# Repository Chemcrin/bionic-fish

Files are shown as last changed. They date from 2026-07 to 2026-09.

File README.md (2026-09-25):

# 仿生鱼工程 · BionicFish

> 一只可在水下游动的仿生潜航器 —— 由**项目组主导、组员协作、AI Agent 辅助**，完成从机械结构设计、电控硬件、嵌入式固件到 Android 上位机的全栈工程实现。外形参考「追鲨一号」构型，结构自主设计。**整机已完成实际下水运行（泳池 / 静水实测）**，面向课程设计、教学演示与水下任务原型验证。

<p align="center">
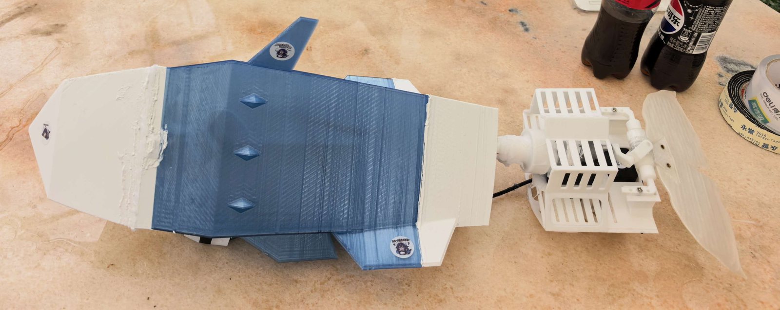
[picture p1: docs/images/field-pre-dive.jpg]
整机下水前实拍
  
</p>
<p align="center"><em>整机实拍 —— 头 / 体 / 尾三段分件，尾部曲柄摇杆传动与尾鳍外露可见</em></p>

<p align="center">
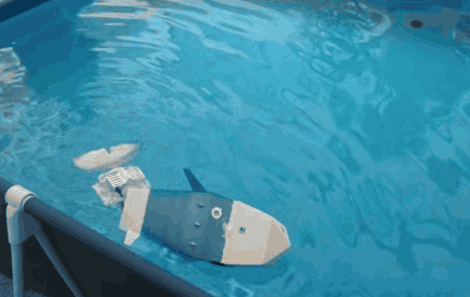
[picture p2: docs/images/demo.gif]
整机在泳池中游动的实拍演示
  
</p>
<p align="center"><em>实机演示 —— 整机在泳池中自主游动，尾鳍摆动推进；完整 24 秒视频见 <a href="docs/media/demo.mp4">docs/media/demo.mp4</a></em></p>

<p align="center">
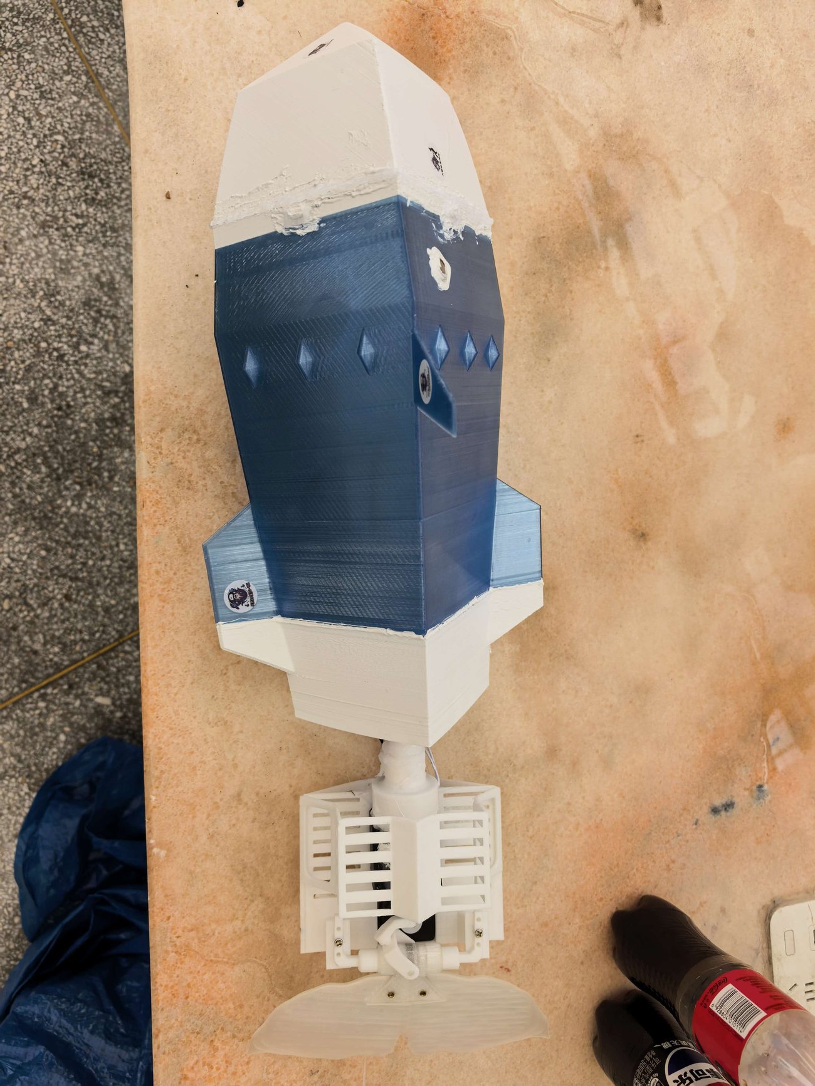
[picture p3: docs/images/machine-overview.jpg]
整机俯视实拍
  
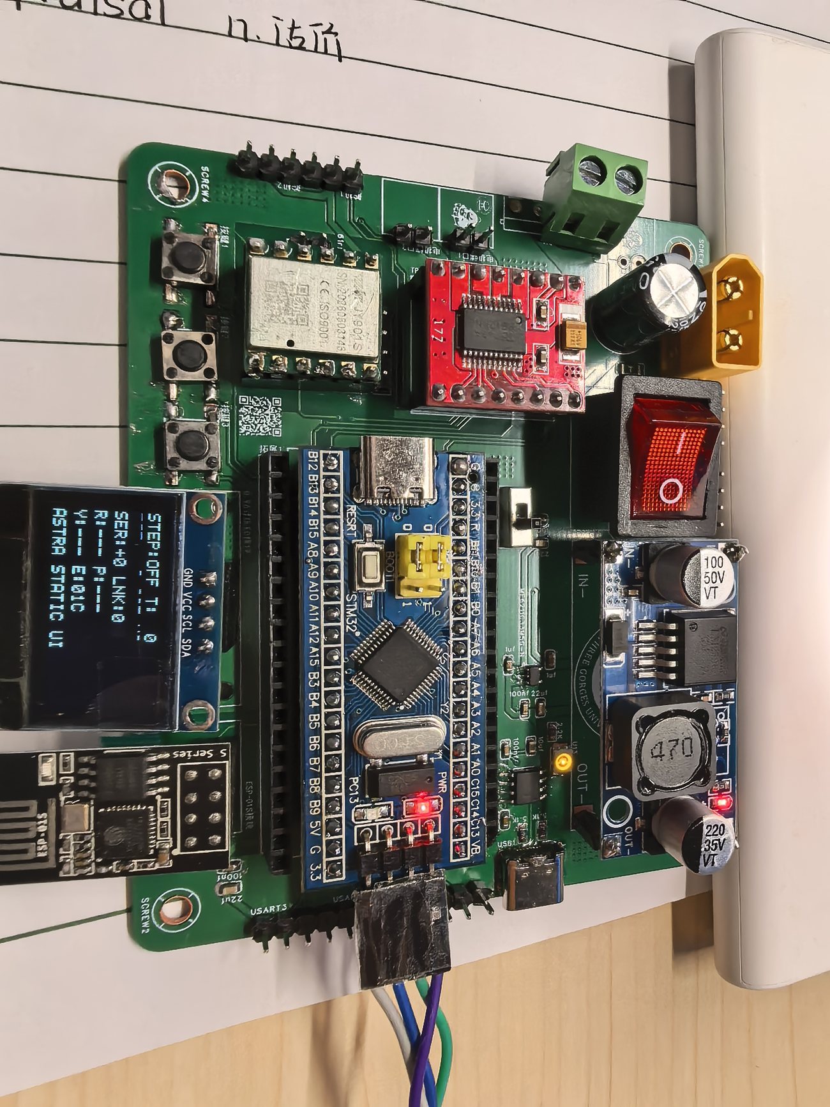
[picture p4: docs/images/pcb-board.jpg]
自研拓展板实装照片
  
</p>
<p align="center"><em>左：整机俯视（白色头部 / 蓝色鱼体 / 白色尾段）；右：自研拓展板实装 —— TB6612、ESP-01S、CH340 + Type-C、OLED、XT60 与 LM2596S 全部可拔换</em></p>

<p align="center">
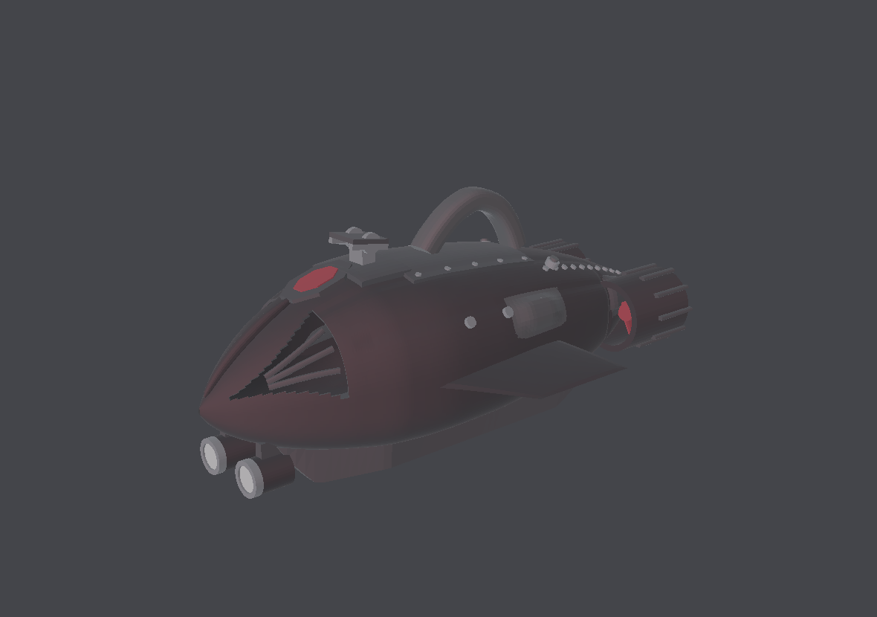
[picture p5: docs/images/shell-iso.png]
外壳外观设计渲染
  
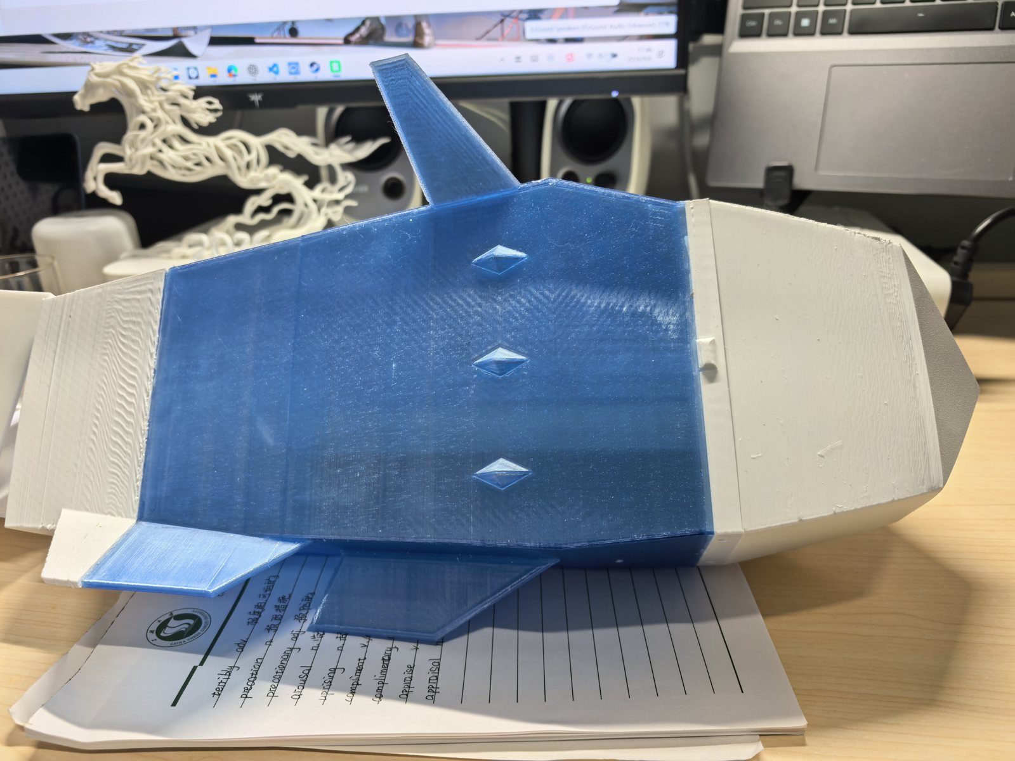
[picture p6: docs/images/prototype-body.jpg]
3D 打印实物
  
</p>
<p align="center"><em>外观设计渲染与 3D 打印实物</em></p>

**开源地址：** [Chemcrin/bionic-fish](https://github.com/Chemcrin/bionic-fish)

> 🤖 **本项目由项目组与 AI Agent 协作开发。** 硬件方案推演、固件与协议实现、上位机、以及本文档本身，都在一个「AI Agent 可闭环」的流程中完成 —— 项目为此专门设计了 **ST-Link SWD 烧录 + 板载 CH340 串口日志**的双通道调试环境（见 [3.5.2](#352-板载-ch340-的实战价值双接-ai-agent-联合调试)），让工具能直接跑通「改代码 → 烧录 → 读日志 → 再改」的迭代闭环。
>
> **如果你也打算复刻，我们鼓励你同样合理地使用 AI 助理工具辅助复刻** —— 让工具去承担资料检索、样板代码、协议解析与日志排错，把人的精力留给机械取舍、电气判断与实机验证。
>
> ⚠️ 但请守住底线：AI 产出的内容**必须经过你自己的复核与实测**。尤其是电源极性、接线顺序、保险丝规格与下水安全相关的部分，**不要未经确认就直接照抄执行**。

---

## 目录

- [一、项目概述](#一项目概述)
- [二、系统总体架构](#二系统总体架构)
- [三、硬件与电气设计](#三硬件与电气设计)
- [四、外观与结构设计](#四外观与结构设计)
- [五、控制方式与通信系统](#五控制方式与通信系统)
- [六、代码架构](#六代码架构)
- [七、上位机与控制台](#七上位机与控制台)
- [八、仓库结构](#八仓库结构)
- [九、快速开始](#九快速开始)
- [📖 复刻指南（硬件制造 / 通信调试 / 电控编写）](docs/复刻指南/README.md)

---

## 一、项目概述

本项目制作一只用于水下任务演示的仿生潜航器。整机以**稳定性与可控性优先**为设计原则，不追求高速。

**这是由项目组主导、组员协作完成的全栈工程** —— 从外形与机械结构设计、电控硬件选型与拓展板搭建、嵌入式固件开发，到 Android 上位机与控制协议定义，均由项目组自行设计与实现（开发全程借助 AI Agent 辅助，见文首说明），未采用现成开源飞控/机器人框架套用。

| 维度 | 指标 |
| --- | --- |
| 外形 | 参考「追鲨一号」潜航器外形，**自主完成整机结构设计**，全长 **700 mm** |
| 壳体 | PETG 3D 打印，壁厚 **3.2 mm**，分段式（头 / 体 / 尾） |
| 推进 | **370 直流减速电机**驱动尾段 |
| 沉浮 | **注射器式浮力调节唧筒**，由 **N20 直流减速电机**（12 V 版）经齿轮螺杆驱动活塞 |
| 转向 | **IP65 舵机**，安全行程 **±15°** |
| 电控 | STM32F103C8T6 主控 + ESP-01S Wi-Fi + TB6612 双 H 桥 |
| 姿态 | JY901S（兼容 JY61P 协议）9 轴 IMU，软件 I²C |
| 显示 | SSD1306 128×64 OLED 单页状态屏 |
| 供电 | 3S 航模锂电池（45C），VM ≈ 12 V |
| 上位机 | Android「仿生鱼控制台」v0.5.0，Wi-Fi TCP AP 直连 |

### 1.1 项目难点与特点

| 特点 | 说明 |
| --- | --- |
| **全栈自研** | 机械结构、电路、固件、协议、上位机 App、网页控制台六层全部由项目组自行打通（全流程有 AI Agent 辅助，见文首说明；制作与验证环节由组员协作承担）。跨层改动需要同时理解机械约束、时序约束与协议兼容性。 |
| **机械结构自主设计** | 外壳、尾部曲柄摇杆传动、唧筒沉浮机构、快拆结构与各支撑件均为自研。尾部支撑经 V2→V3R→V4R→**V6/V4F** 多轮迭代收敛；唧筒从零设计出「N20 + 齿轮减速 + 螺杆自锁 + 双微动开关限位」的完整传动链。 |
| **参数化外壳建模** | 用 Python 以型线表驱动生成 700 mm 整机外观（90,068 三角面），改参数即可调整线型，再导出 STL/STEP 供 3D 打印与 CAD 后续加工。 |
| **从零定义通信协议** | 自研 V1 ASCII 协议：换行分帧、序号窗口防重放与乱序、故障位图并存多故障、失联 1 s 安全停机。协议同时被 Android App 与板载网页控制台复用。 |
| **裸机实时固件** | 6,000 行 C，无 RTOS，64 KiB Flash / 20 KiB RAM 内跑通双电机、舵机、IMU、OLED、TCP 服务与网页托管。 |
| **可替换、可观测的硬件设计** | 自研拓展板：32 针母座固定核心板、UART 与电机舵机接口全排针扇出、全模组可拔换；板载 CH340 与 SWD 构成**双通道并行调试**，为 AI Agent 辅助开发提供了可闭环的烧录 + 日志通路。 |
| **板级电气与电源自主设计** | 逻辑轨用 ME6211 LDO（低噪声，护住 IMU），动力轨用 LM2596S DCDC（高效率，带电机）；XT60 与咪头双输入适配，5 A 一次性保险丝兜底短路保护。 |
| **踩穿硬件级陷阱** | 自行定位 100% 占空比导致 TB6612 自举电容无法刷新的隐性故障，并留下编译期门禁防止同类问题静默复发（见第三章 3.4）。 |
| **已实际下水运行** | 整机装配完成后**真实入水运行**，在泳池 / 静水环境验证密封、配重、姿态与基本机动（前进、转向、安全停机），不是只停留在台架或仿真阶段。 |

**首版定位**：无线遥控 + 半自动控制原型，核心目标是验证「能游、能控、能安全停机」—— 该目标已通过整机下水实测确认；视觉自主与深度闭环留待第二阶段增强。

> ⚠️ 本项目为教学原型，**已在泳池 / 静水环境完成整机下水运行实测**。但**长时间深水作业、复杂水域与自主任务能力尚未验证**；软件测试通过也不等于任意环境下都可用。每次下水前仍请确认已装好机械保护、可立即断电，并已完成台架启停、失联与供电恢复测试。

> 📌 **关于文中「需实测确认」的表述**：软件层证据（host 回归、Android 单元/仪器测试、实板烧录与 USART3 诊断）与整机下水是**两套独立证据**。文中标注为「待实板」「需实测」的条目，指**尚未做过逐项定量标定**的项目（如堵转电流、TB6612 温升、动密封长期衰减），不代表整机未下水。

---

## 二、系统总体架构

```text
┌──────────────────────────────────────────────┐
│         Android 控制台「仿生鱼控制台」          │
│   M1 方向 ／ M2 唧筒 ／ 舵机 ±15° ／ 急停       │
└───────────────────┬──────────────────────────┘
                    │ Wi-Fi：BionicFish-AP
                    │ TCP 192.168.4.1:9000
┌───────────────────▼──────────────────────────┐
│              ESP-01S（ESP8266）               │
│   AT 固件 1.7.4.0 ｜ 纯 SoftAP ｜ TCP Server   │
└───────────────────┬──────────────────────────┘
                    │ UART0 ↔ USART2　115200-8N1　无流控
┌───────────────────▼──────────────────────────┐
│           STM32F103C8T6　SYSCLK 72 MHz        │
│  ┌────────────────────────────────────────┐  │
│  │ TIM2 ── PWM ──► TB6612 ─┬─ A 桥 ─► M1 370 推进 │
│  │                         └─ B 桥 ─► M2 N20 唧筒 │
│  │ TIM3 CH1 ── 50 Hz 脉冲 ──► 舵机 PA6     │  │
│  │ 软件 I²C PB6/PB7 ──► JY901S 姿态         │  │
│  │ 软件 I²C PB8/PB9 ──► SSD1306 状态屏      │  │
│  │ USART3 ──► CH340 ──► 调试/诊断输出      │  │
│  └────────────────────────────────────────┘  │
│  ▲ 32 针母座固定 ── UART/电机/舵机全排针扇出   │
└──────────────────────────────────────────────┘
        ▲ SWD                              ▲ USART3
   ┌────┴─────┐                      ┌─────┴──────┐
   │ ST-Link  │                      │ CH340(Type-C)│
   └────┬─────┘                      └─────┬──────┘
        └────────► 同一台主机 ◄────────────┘
              烧录 + 串口日志 双接并行调试
```

**电源链路**：

```text
XT60 / 咪头 ──► 5 A 一次性保险丝 ──► LM2596S (DCDC, 可调)
                                        │
                              ┌─────────┴──────────┐
                              ▼                    ▼
                        动力轨：TB6612 VM、舵机   5 V 中间轨
                                                   │
                                                   ▼
                                        ME6211 (LDO) ─► 3.3 V 逻辑轨
                                        MCU / ESP / IMU / OLED / CH340
```

**两条执行链路分工**：

- **M1（370）→ 尾段推进**：决定「往哪游」，通过尾段摆动产生前进推力与航向；
- **M2（N20）→ 唧筒活塞**：决定「在哪个深度」，通过注射器式容积变化改变排水量，从而调节浮力实现上浮/下潜。

这两路共用一个 TB6612 的两个 H 桥，因此**共用同一 PWM 挡位**，但方向各自独立 —— 推进与沉浮可以同时动作。

**信息流是双向的**：命令从 Android 经 ESP 下达到 STM32；状态帧（`STA`）从 STM32 周期回传，经 ESP 与 CH340N 双路输出，让手机端与串口调试端能同时观察整机状态。

---

## 三、硬件与电气设计

### 3.1 选型对比与决策依据

> 📐 **总体设计思路沿用 TI 杯电子设计竞赛的工程范式**：主控 + 功能模组的积木式组合，每个模组独立供电、独立接口、可单独替换与单独测试，全链路信号都留可测量的测试点。这一取向直接决定了下面几乎每一行的取舍 —— 宁可多花几块钱买成熟模组，也不把风险藏进自绘 PCB 里。

| 环节 | 候选方案 | 最终选择 | 适宜性 | 经济性 | 稳定性 |
| --- | --- | --- | --- | --- | --- |
| **主控** | STM32F103ZET6 / **C8T6** / ESP32 单主控 | **STM32F103C8T6** | 需 5 路 PWM + 2 路 UART + 2 路软 I²C，C8T6 的 37 个 GPIO、16 路定时器通道完全覆盖且有余量；硬件 FPU 与算力对本任务无刚需 | LQFP48 最小系统板约 ¥10–15，远低于 ZET6；生态成熟、资料丰富 | 工业级 Cortex-M3，HAL 库稳定；无操作系统裸机调度，无 RTOS 任务抖动风险 |
| **板级架构** | 自绘一体式 PCB / **核心板 + 拓展板** | **核心板 + 自研拓展板** | 拓展板只做引脚扇出与电源分配，不做信号处理，故障定位边界清晰；核心板可单独取下用 ST-Link 烧录与替换 | 拓展板单次打样即可，改版只需重画扇出层，不牵动主控电路 | 任一功能模组异常时可直接拔换排查，不必怀疑板上焊接；核心板损坏只需换最小系统板 |
| **调试 / 烧录** | 仅 SWD / 仅串口 / **SWD + 板载串口双通道** | **ST-Link SWD + 板载 CH340 Type-C 双接** | 两种通道各司其职：SWD 负责烧录与断点，CH340 负责运行期日志与协议观测 | CH340 芯片约 ¥2，省掉一个外置 USB-TTL 模块与接线工序 | 双通道互为备份；SWD 被占或接触不良时，串口仍能观察到状态帧 |
| **无线通信** | 自绘 ESP8266 透明桥 / ESP32 WebSocket / **ESP-01S AT** | **ESP-01S + AT 固件** | 只需 TCP 透传，AT 模式无需自维护固件；UART 一条线接入即可 | 模组约 ¥8，无需额外 PCB 打样与烧录工装 | 官方 AT 固件经长期验证；每次 AT 事务带响应确认，链路状态可观测 |
| **电机驱动** | L298N / **TB6612FNG** / 分立 MOS H 桥 | **TB6612FNG** | 单芯片双 H 桥，正好驱动 M1 推进与 M2 唧筒两路，PWM 频率范围宽 | 模块约 ¥6，比 L298N 便宜且体积小一半 | 导通电阻低、发热小、自带热关断；无需自绘 H 桥即可获得可靠驱动 |
| **推进方式** | 42 两相双极步进 / **直流减速电机** | **370 直流减速电机** | 直流电机直接调压调速，无需换相表、相序配对与步距角标定，工程复杂度大幅下降 | 370 减速电机约 ¥15，无需专用步进驱动器 | 两根线接入，接反只会反转，不会像步进那样抖动/堵转；无失步风险 |
| **沉浮方式** | 中性浮力 + 鳍面控制 / 可移动配重 / **注射器式唧筒** / 微型水泵 | **注射器式浮力调节唧筒**（N20 驱动） | 通过活塞改变排水体积主动调节浮力，可**原地定深**，不依赖前进速度；相比水泵方案无管路与水泵密封难题 | 100 ml 注射器 + N20 减速电机 + 齿轮螺杆，成本远低于水泵浮力舱 | 机械容积式调节，状态可复现；配双微动开关做行程限位 |
| **姿态传感器** | MPU6050 / **JY 系列** | **JY901S**（兼容 JY61P） | 模块内部完成姿态解算，直接读角度寄存器，主控零算力开销 | 约 ¥50，省去自写互补滤波/Kalman 的开发成本 | 内部温补与磁力计融合，Yaw 为绝对航向而非陀螺积分漂移 |
| **舵机** | 普通舵机 / **IP65 防水舵机** | **IP65 防水舵机** | 水下环境刚需 | 略贵但省去额外防水结构 | 工厂封装防水，可靠性远高于自制密封 |
| **显示** | 无 / **SSD1306 OLED** | **SSD1306 128×64** | 自写单页状态屏即可，不引入图形库 | 约 ¥8 | 免背光、低功耗、I²C 两根线接入 |
| **降压（逻辑轨）** | AMS1117 / **ME6211** / 7803 | **ME6211（3.3 V LDO）** | 压差仅约 100 mV 级，可直接从 5 V 或单节锂电落到 3.3 V，静态电流低 | 单价约 ¥0.5，比 AMS1117 更便宜 | LDO 无开关噪声，适合给 IMU 与 MCU 供电；外围仅需两颗电容 |
| **降压（动力轨）** | 7805 线性 / **LM2596S** | **LM2596S（DCDC）** | 2 A 级输出、可调，覆盖舵机与 12 V 电机轨；开关式效率远高于线性 | 模块约 ¥3，是同级 DCDC 里最便宜的量产件 | 内置限流与热关断；成熟度高，datasheet 与参考设计极为充分 |
| **电源输入** | DC 圆孔 / JST / **XT60 + 咪头双适配** | **XT60 主接口 + 咪头备用** | 主电池走 XT60 保证大电流接触；咪头作为细线备用输入，便于台架接稳压源 | 两个接口合计约 ¥2 | XT60 接触电阻低、极性防呆、可反复插拔；双接口任一路径断线仍可供电 |
| **保护** | 无 / 自恢复保险丝 / **一次性保险丝** | **5 A 一次性保险丝** | 整机峰值电流按 2 A 级设计，5 A 留约 2.5 倍余量，足够抗电机堵转启动冲击 | 单价可忽略 | 熔断特性确定性高于自恢复件，短路时彻底切断，不会反复通断拉弧 |

### 3.2 关键决策：为什么放弃步进电机

早期方案采用「**42 两相双极步进电机 + 软件四拍换相**」驱动尾段，实现中发现三个问题：

1. **换相复杂**：需要维护换相表、相序配对、步距角与减速比标定，且两个桥必须分别驱动两组线圈；
2. **失步不可观测**：无编码器时，步进电机的开环特性无法判断是否丢步，而本体又受水流扰动；
3. **驱动余量不足**：TB6612 单通道 1.2 A 为绝对最大额定值，3.2 A 仅 10 ms 单脉冲条件，驱动步进线圈的余量偏紧。

最终 TB6612 的两个 H 桥改为各驱动一台**有刷直流减速电机**：

- **M1（370）→ 尾段推进**：主推力来源，决定游动方向；
- **M2（N20）→ 唧筒活塞**：驱动注射器活塞推拉，改变排水量实现沉浮。

直流电机不需要换相节拍，启停与换向只由 `IN1/IN2` 两个 GPIO 决定，代码与调试路径都显著简化。

> 📌 `42HS34-FS.STEP` 等步进相关模型属于**已作废方案**，与尾段推进的现状无关，请勿据此推断额定参数。这些遗留件不随仓库发布。

### 3.3 引脚分配

| 功能 | 信号 | STM32F103C8T6 引脚 | 配置与边界 |
| --- | --- | --- | --- |
| MCU / 时钟 | — | — | 64 KiB Flash、20 KiB RAM；HSE 8 MHz × PLL9 = **SYSCLK 72 MHz** |
| M1 PWM（370 推进） | `PWMA` | **PA0** | TIM2_CH1，接 TB6612 A 桥，占空比随挡位取 95% / 60% |
| M2 PWM（N20 唧筒） | `PWMB` | **PA1** | TIM2_CH2，接 TB6612 B 桥，两路共用同一挡位 |
| M1 方向 | `AIN1/AIN2` | **PB12 / PB13** | 推挽 GPIO，决定 A 桥电流方向与 coast |
| M2 方向 | `BIN1/BIN2` | **PB14 / PB15** | 推挽 GPIO，决定 B 桥电流方向与 coast |
| 唧筒限位 | 微动开关 ×2 | 待接 | 活塞行程两端限位，防止螺杆顶死堵转（机械件已建模） |
| STBY | `STBY` | PB5（可选） | **当前默认不占用**，实物 STBY 恒接 3.3 V 高电平 |
| 舵机 | `SIG` | **PA6** | TIM3_CH1，50 Hz、1000–2000 µs，中位 1500 µs |
| ESP 通信 | `USART2` | **PA2 / PA3** | PA2→ESP RXD，ESP TXD→PA3；115200-8N1，无 RTS/CTS |
| 调试输出 | `USART3` | **PB10 / PB11** | 接 CH340N；仅输出诊断与状态帧，不接收控制命令 |
| 姿态 IMU | `SCL / SDA` | **PB6 / PB7** | 独立 GPIO 开漏软件 I²C，**需外接 4.7 kΩ 上拉到 3.3 V** |
| OLED | `SCL / SDA` | **PB8 / PB9** | 独立 GPIO 开漏软件 I²C，模块自带板载上拉 |
| 调试按键 | `K1/K2/K3` | **PB0 / PB1 / PA8** | 低电平有效、内部上拉；⚠️ 下水前须关闭 |
| 运行指示 | — | **PC13** | GPIO 输出，正常每 500 ms 翻转 |
| 烧录 | `SWDIO/SWCLK` | **PA13 / PA14** | 保留调试，禁止改作业务 GPIO |

> 两条软件 I²C 总线**互相独立**：`I2CSCAN` 报 OLED 总线（PB8/PB9）、`IMUSCAN` 报 IMU 总线（PB6/PB7），互不代表对方的结论。

### 3.4 一个典型的硬件陷阱：为什么满速挡是 95% 而不是 100%

台架调试时出现「**VM = 12 V、STBY 已拉高，电机却带不动负载**」。定位过程：

- 100% 占空比在 STM32F1 上落成 `CCR = ARR + 1`，比较输出**恒为高电平、永不翻转**；
- TB6612 的 PWM 输入依赖**持续的开关边沿**维持高侧栅极/自举驱动，恒定高电平会让自举电容无法刷新；
- 结果：高侧开关无法持续导通 → 电机只有微弱/断续驱动能力。

**修正**：占空比降到 **95%**，保证每个载波周期都有一次完整低电平沿；同时把 TIM2 载波周期由 20 kHz 改为 **2 s**（0.5 Hz），让一个周期内的高电平成为「一整段连续导通」，电机看到近似直流而非斩波。

代价与收益：95% × 12 V = **11.4 V**，转速与扭矩相对满压几乎无损；2 s 慢周期下「>0 且 <100」的占空比会产生明显脉动，因此若不需要调速应优先用满速挡。

> 📌 这个坑不在任何数据手册的显著位置，却直接决定整机能否推动负载。记录在此供复刻者避坑。

---

### 3.5 拓展板：把「可替换」做进电路里

硬件全部集成在一块自研拓展板上，核心板通过母座插在板上。整块板的设计目标只有一句话：**任何一路模块出问题，都应该是拔下来换掉，而不是拿烙铁上去查。**

<p align="center">
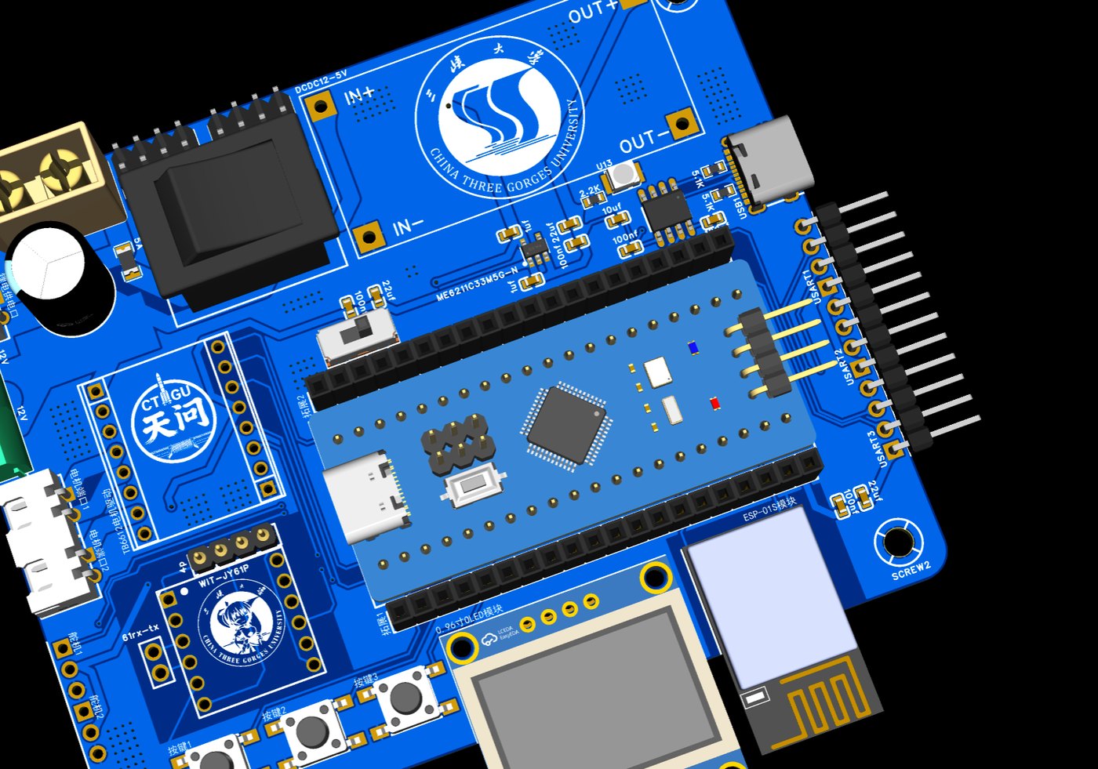
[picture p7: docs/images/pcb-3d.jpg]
拓展板 PCB 3D 设计视图
  
</p>
<p align="center"><em>拓展板 PCB 3D 设计视图（立创EDA）—— 丝印上标出了每个模组的插接位置与信号名，装配时对着丝印插即可</em></p>

#### 3.5.1 连接器与接口

| 设计点 | 做法 | 解决什么问题 |
| --- | --- | --- |
| **32 引脚母座** | STM32 核心板以直插母座固定，不使用焊死方案 | 主控可整体拔下单独烧录/替换；换核心板不影响板上任何走线 |
| **排针扇出** | UART 与电机、舵机接口**全部引出排针** | 杜邦线即可外接新模组，无需飞线焊点；台架阶段可临时并联示波器或逻辑分析仪探头 |
| **全模块可拆卸** | TB6612、ESP-01S、JY901S、OLED 均经排针/排母连接 | 逐个替换即可定位故障；测试时可用同型号备件直接交叉换件 |
| **双通道调试** | ST-Link SWD（`PA13/PA14`）+ 板载 CH340（`USART3`） | SWD 负责烧录与断点，CH340 负责运行期日志；两者可**同时连接** |
| **Type-C 直连** | 板载 CH340 引出 Type-C 母座 | 一根普通手机线即可接电脑看串口，不必再找 USB-TTL 转接板 |

#### 3.5.2 板载 CH340 的实战价值：双接 AI Agent 联合调试

这是本项目在调试方式上最有价值的一处设计。把 **SWD 与串口同时接到同一台电脑**，就构成了一个「Agent 可闭环的调试环境」：

```text
┌──────────────┐   SWD（烧录/断点/寄存器）  ┌────────────────┐
│  ST-Link     │◄──────────────────────────►│                │
└──────────────┘                            │  STM32F103C8T6 │
┌──────────────┐   USART3（日志/状态帧）     │  拓展板         │
│  CH340(Type-C)│◄──────────────────────────►│                │
└──────┬───────┘                            └────────────────┘
       │ 两条独立 USB 通道同时挂在同一台主机上
┌──────▼───────────────────────────────────────┐
│  AI Agent（可读串口日志 + 可下载固件 + 可复位）  │
└──────────────────────────────────────────────┘
```

**为什么这对 AI Agent 辅助开发是决定性的**：Agent 需要「**改代码 → 烧录 → 看现象 → 再改**」形成一个可自动执行的闭环。

- **能烧**：SWD 通道让 Agent 可以直接下载固件、复位、halt 查看寄存器，不必人工点 IDE；
- **能看**：CH340 通道把 `ESP server=… tcp=… reset=… error=…`、`IMU scl= sda= st= probe=`、`STA` 状态帧全部以**纯文本**形式吐到串口，Agent 无需摄像头或人工转述就能读到设备的真实状态；
- **可交叉验证**：一旦 SWD 侧异常（如烧录报错、连接不上），串口侧仍在独立输出，能立刻区分「是固件没跑起来」还是「是调试器/接线的问题」。

CH340 与 SWD 使用**完全独立的物理通道**，互不抢占资源，因此可以长期保持双接状态。协议本身也为此做了配合：选用**可打印 ASCII + 换行分帧**（见第五章），就是为了让串口日志能被工具与 Agent 直接解析，而不是面对一串需要额外解码的二进制。

> 📌 这里有一个真实踩过的坑：早期调试曾出现 `failed to erase memory`，正是先靠**串口侧日志与 RAM 读写对照实验**排除了 MCU 内部 flash 控制器故障，才没有误判为固件问题（见 [9.4 节](#94-常见故障排查)）。

---

### 3.6 电源架构

#### 3.6.1 双 LDO / DCDC 分工

电源设计上刻意做了**逻辑轨与动力轨分离**，避免电机启停的电流冲击与开关噪声污染 MCU 与 IMU：

| 轨道 | 器件 | 输入 → 输出 | 供给对象 | 选型理由 |
| --- | --- | --- | --- | --- |
| **3.3 V 逻辑轨** | **ME6211**（LDO） | 5 V 中间轨 → 3.3 V | STM32、ESP-01S、JY901S、OLED、CH340 逻辑 | 压差小、静态电流低、**无开关噪声**，姿态传感器对电源纹波敏感，LDO 是更稳的选择；成本约 ¥0.5 |
| **动力轨** | **LM2596S**（DCDC） | 电池 → 电机/舵机电压 | TB6612 的 VM、舵机 | 开关式效率高、可调、2 A 级输出，带电机这类非线性负载时发热远小于线性方案 |

分工的核心考虑是**噪声敏感度**：LDO 效率低但干净，适合 mA 级、怕纹波的逻辑器件；DCDC 有开关纹波但效率高，适合 A 级、不在乎纹波的动力器件。两者各管一段，不在同一条轨上妥协。

> 📌 DCDC 的可调输出先落到 **5 V 中间轨**，再由 ME6211 降到 3.3 V。这样做的原因有二：其一，部分模组（舵机、CH340）需要 5 V 而非 3.3 V；其二，**两级降压的单级压差都更小、发热更可控**，比直接从电池一次跳到 3.3 V 更稳。

#### 3.6.2 输入接口与保护

```text
        ┌──────────────┐
   XT60 ┤              │
        │  5 A 一次性   ├──► LM2596S ─┬─► 动力轨（电机 / 舵机）
  咪头  ┤   保险丝      │            │
        │              │            └─► 5 V 中间轨 ─► ME6211 ─► 3.3 V 逻辑轨
        └──────────────┘
```

| 项 | 设计 | 说明 |
| --- | --- | --- |
| **主电源接口** | **XT60** | 大电流下接触电阻低、有极性防呆、可反复插拔，是航模电池的标准接口 |
| **备用输入** | **咪头接口** | 与 XT60 双适配；台架调试时可接实验室稳压电源，不必拆电池 |
| **过流保护** | **5 A 一次性保险丝** | 整机峰值按 2 A 级设计，5 A 留约 2.5 倍余量以容忍电机堵转启动的瞬时冲击；选一次性而非自恢复型，是为了短路时**彻底切断**，避免自恢复件反复通断造成拉弧与二次损伤 |

> ⚠️ 保险丝**只保护短路与严重过流，不保护接反**。上电前务必确认 XT60 极性；电池正负极接反会直接击穿稳压模块与所有模组。
>
> 📌 上述电源架构以**当前实装版本**为准。早期阶段 B 设计文档中曾规划过更复杂的多轨电源树（含升压轨与 PCA9685 舵机轨），属于历史方案，与本机现状不一致。

---

## 四、外观与结构设计

> **设计归属说明**：本章结构设计由**项目组自主完成**（组员协作参与建模与实物验证）。外观上**参考了「追鲨一号」潜航器这一公开外形作为风格参考** —— 即借鉴其整体构型语汇（盾形前脸、三角侧翼、圆筒尾部护罩、顶部把手等）作为设计起点，**并非照搬或复刻其模型**；所有尺寸、型线、分件与内部结构均为项目组自主设计与权衡的结果。
>
> Python 参数化脚本在此仅作**辅助工具**：用于快速试算线型、批量生成预览渲染与导出打印用网格，方便迭代。**真正的结构设计（分件方式、装配接口、壁厚与打印方向、内部承载与密封）以 SolidWorks 手工建模与人工判断为准**，脚本不能替代设计决策。

### 4.1 外壳外观设计

外壳以「追鲨一号」**外形风格为参考**自研设计，兼顾水动力外形与 3D 打印可行性。设计要点：

| 部位 | 设计 |
| --- | --- |
| **上壳** | 连续凸面 + 纵向分割缝 + 螺钉列，顶部中央设备/电池舱盖 |
| **下壳** | 浅凹底板 + 纵向导流槽（型线指数取 3.5–3.7 得到「平面或浅凹」效果） |
| **侧翼** | 三角形，前缘直、后缘收拢、略下倾，下反 18 mm |
| **前脸** | 盾牌轮廓 + 中央竖脊；左右三角格栅 + 内部肋条（**真实通孔**） |
| **双灯** | 前下方并列双圆灯 ⌀44 mm，机腹前缘下方短支架安装 |
| **尾部** | 圆弧收尾 + 左右推进器护罩 ⌀98 mm + 中央轴向护罩 ⌀92 mm |
| **把手** | 顶部拱形枪柄式把手，拱高约 60 mm（弧顶即整机最高点） |
| **滑橇** | 底部纵向加强梁，前端接灯支架 |

**进水设计**：前脸左右格栅、腹部 4 条进水槽、尾部推进器开口均为**真实通孔**，且沿孔边生成 3.2 mm 壁厚翻边 —— 不是贴图或凹槽。

<p align="center">
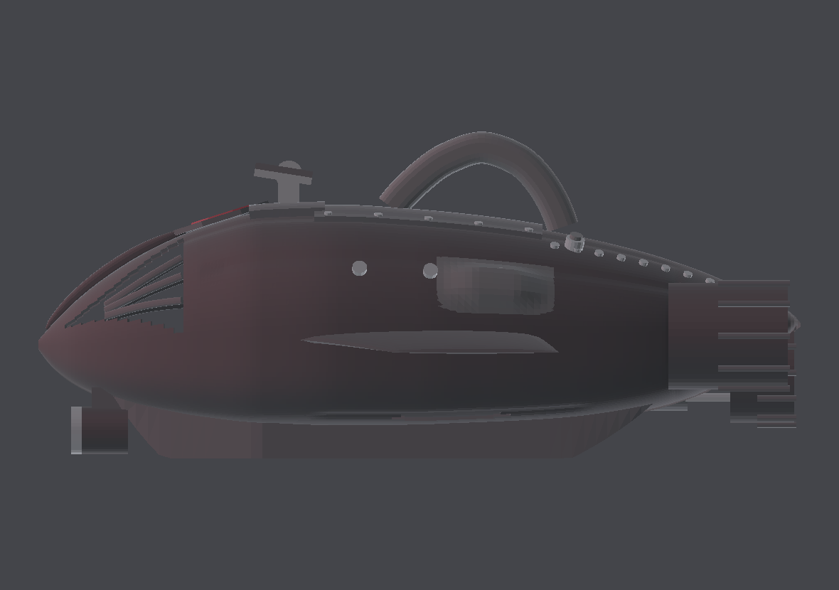
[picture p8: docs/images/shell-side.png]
外壳侧视渲染
  
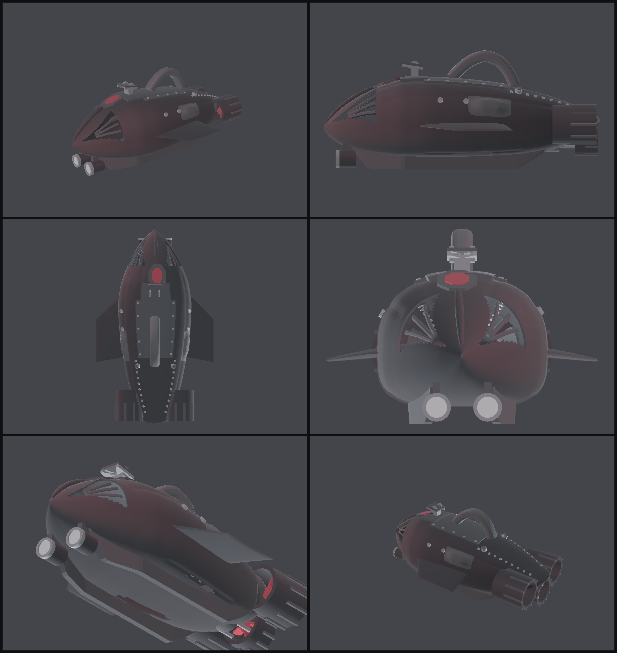
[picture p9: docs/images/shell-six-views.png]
外壳六视图
  
</p>
<p align="center"><em>外壳外观设计：侧视渲染与六视图预览</em></p>

### 4.2 关键尺寸

| 项 | 数值 | 说明 |
| --- | --- | --- |
| 总长 X | **700.0 mm** | x = 0 为鼻尖 |
| 壳体壁厚 | **3.2 mm** | 建议区间 2.5–4 的中值 |
| 三角面数 | 90,068 | 完整外观网格 |

坐标系：`+X` 纵轴向后，`+Y` 右舷，`+Z` 向上（z = 0 为滑橇触地面），单位 **mm**。

> ℹ️ 上述外观网格由辅助脚本按人工给定的型线表生成，型线比例经目测推定而非实测图纸；横向尺寸未单独标定，制造前需按实物重新测量。

### 4.3 设计流程与可调参数

**设计主线**：项目组先在 SolidWorks 中确立分件方案与关键结构，再借助 Python 脚本把定义好的型线快速展开成完整网格，用于预览渲染与打印试制；需要修改外形时改脚本参数即可快速试算，最终结构仍以 CAD 模型为准。

辅助脚本的核心参数集中在 `model.py` 顶部：

```python
L_TARGET = 700.0     # 总长，最后等比缩放到该值
THICK    = 3.2       # 壳体壁厚
NX, K    = 232, 34   # 纵向站数 / 每象限截面点数

#      鼻尖 x=0 .......................................... 尾尖 x=712
XS   = [0,   14,  35,  70,  105, 154, 210, 280, 350, 420, 490, 560, 616, 658, 700, 708, 712]
WID  = [1.5, 18,  40,  66,  86,  108, 126, 134, 131, 123, 112, 98,  82,  66,  44,  28,  2.0]  # 半宽
ZTOP = [118, 134, 155, 182, 203, 224, 238, 240, 236, 229, 218, 202, 184, 166, 146, 139, 134]  # 上缘
ZWL  = [114, 112, 112, 114, 117, 120, 123, 125, 125, 125, 125, 126, 128, 131, 134, 135, 133]  # 最宽线
ZBOT = [110, 92,  76,  60,  50,  41,  35,  34,  34,  36,  40,  50,  66,  90,  120, 128, 131]  # 下缘
NUP  = [...]         # 上半截面超椭圆指数，越大越"方"
NLO  = [...]         # 下半截面指数
```

改完参数直接重建：

```bash
python modeling/build.py          # 加 --no-render 可跳过预览渲染（渲染约 20 s）
```

**生成产物**：完整外观网格（STL/OBJ/MTL）、头/体/尾分段 STEP（0–180 / 180–520 / 520–710 mm）、面片化 STEP 参考装配、六视图预览。这些产物用于**预览与打印试制**，制造级结构仍需在 SolidWorks 中完成（见 4.6）。

<p align="center">
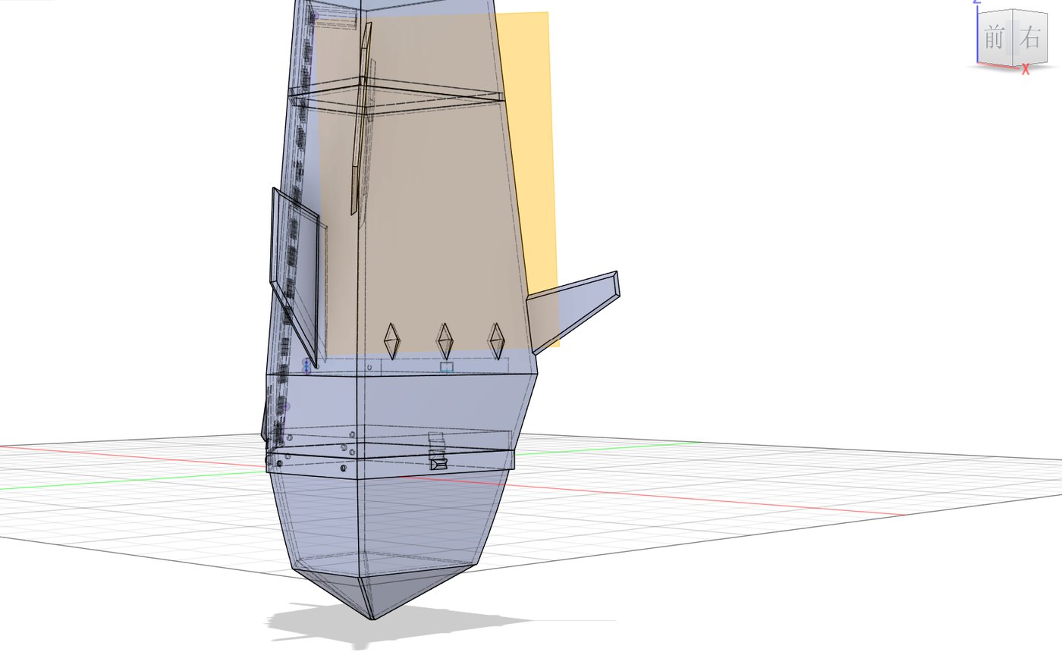
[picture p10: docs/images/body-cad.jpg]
鱼体 CAD 模型正视图
  
</p>
<p align="center"><em>鱼体在 CAD 中的正视图 —— 型线剖面、分件接缝与侧面菱形开口／舷鳍安装面</em></p>

### 4.4 沉浮机构：「唧筒」浮力调节

沉浮采用**注射器式浮力调节**方案，是整机仅次于推进机构的第二套关键机械系统。核心思路：通过改变鱼体排水体积主动调节浮力，从而**不依赖前进速度即可原地定深**。

```text
N20 直流减速电机
    │
    └─► 马达齿轮 ──► 大齿轮（减速）──► 螺杆 ──► 活塞
                                          │
                            100 ml 注射器筒体 ──► 排水体积变化
                                          │
                          微动开关 ×2 ◄────┴──── 行程两端限位
```

| 零件 | 作用 |
| --- | --- |
| N20 电机模型 | 动力源，12 V 直流减速电机 |
| 马达齿轮 / 大齿轮 | 减速增扭，把电机转速降到活塞可用的推拉速度 |
| 螺杆 / 自锁六角螺母 | 将旋转运动转为直线运动；螺纹自锁保证断电后活塞不回退 |
| 活塞 / 100 ml 活塞底座 | 推拉改变注射器内容积 |
| 唧筒 / 唧筒盖 / 唧筒顶 / 唧筒注射器 | 筒体与密封结构 |
| 微动开关 ×2 / 限位触发轴 | 活塞行程两端限位，防止螺杆顶死导致堵转 |

**为什么选这条路**：早期计划书里比较过四种沉浮方案，最终选择唧筒式而非「中性浮力 + 鳍面控制」，原因是后者需要持续前进才能产生升沉力，**低速或原地无法定深**；而水泵方案虽然也能主动调节，但管路与水泵的密封复杂度高得多。唧筒式是机械容积调节，状态可复现，且**螺纹自锁天然提供断电保位**。

> 📌 唧筒的**限位开关接线尚未纳入当前固件**，活塞行程保护需在实机联调时补充。

### 4.5 结构件自主设计与迭代

除外壳与唧筒外，尾部装配是机械设计的核心，也是自主设计中投入迭代最多的部分。相关件均从零绘制，经多轮修改收敛：

| 零件 | 最终版本 | 说明 |
| --- | --- | --- |
| 尾部支撑 | **左支撑 V6F / 右支撑 V4F** | 自研件，经 V2 / V3R / V4R 多轮迭代收敛，是尾段承载与传动的基准 |
| 传动 | 套筒、摇杆、`moto shef`（电机座）、U 型件 | 曲柄摇杆式尾段传动，零件均为自主建模 |
| 关节 | 鱼体第二关节 | 分段装配接口，兼顾装配精度与打印分件 |
| 快拆 | 快拆架、防水盒快拆 | 便于检修与电池更换 |

**迭代过程的取舍**：尾部支撑从 V2 到 V6F/V4F 的演进中，反复调整了传动力臂、支撑刚度与打印方向之间的平衡 —— 早期版本偏重外形贴合，后期版本为保证电机负载下的结构刚性而增加了加强筋与壁厚。这类权衡是纯脚本无法代劳的设计决策。

<p align="center">
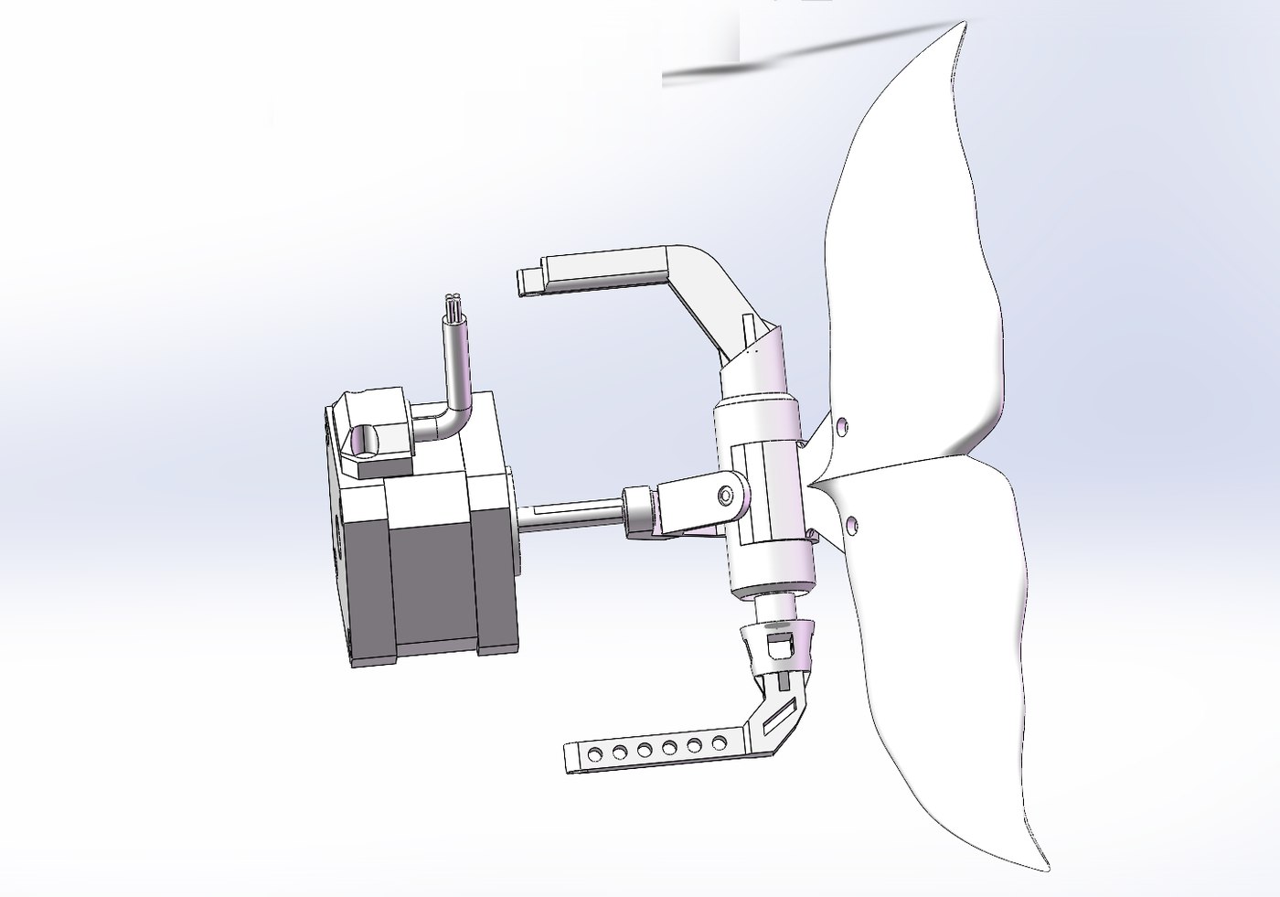
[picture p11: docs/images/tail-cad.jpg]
尾部曲柄摇杆传动装配（CAD 装配体）
  
</p>
<p align="center"><em>尾部传动装配（CAD）—— 电机座 → 曲柄 → 摇杆 → 尾鳍，支撑件即上表中的 V6F / V4F</em></p>

> 📦 **可发布的尾段零件已整理至仓库根目录 [`鱼尾装配/`](鱼尾装配/README.md)**，含上述最终版零件、装配体与一份零件清单说明，复刻者可直接取用。
>
> 📌 早期版本（V0.2 / V3R / V4R / draft）与完整建模工作区已归档至本地 `建模/`，**不随仓库发布**，避免复刻者误用过期尺寸。已废弃的步进方案件（`42HS34-FS.STEP`、`步进支架.step`）同样不发布。

### 4.6 已知结构局限

- 开口边缘沿网格四边形量化，放大看有轻微台阶；制造级模型需在 CAD 中用裁剪曲面重建开口。
- 内部电气（电池盒、控制器）未建模 —— 原型说明明确了「不必照搬内部电气尺寸」。
- 辅助脚本产出的网格为多部件叠加，**非单一水密实体**；直接 3D 打印前需先在 CAD / 切片软件中做布尔合并。
- 制造级工作（止口、密封槽、螺钉孔、装配间隙）需在 SolidWorks 中完成，脚本产物定位为外观与装配参考，不作为最终加工依据。
- STEP 采用每个源三角面对应一个平面面的 **faceted B-REP**，非参数化 NURBS，不保证导入后自动成为水密实体。
- 唧筒活塞在注射器筒体内的**动密封**是全机防水的关键风险点：已随整机下水运行验证可用，但长期往复后的密封衰减、以及深水压力下的表现尚未做过定量测试。

---

## 五、控制方式与通信系统

### 5.1 通信链路

```text
Android ── Wi-Fi (BionicFish-AP) ──► ESP-01S ── UART0/USART2 ──► STM32
                                                                   │
Android ◄── Wi-Fi ◄── ESP-01S ◄── USART2 ────────────────────────┤
                                                                   │
                                         CH340N ◄── USART3 ◄───────┘
```

| 参数 | 值 |
| --- | --- |
| SSID / 密码 | `BionicFish-AP` / `12345678` |
| AP / 网关 | `192.168.4.1` |
| 掩码 | `255.255.255.0` |
| 传输 | TCP Server，端口 `9000` |
| Wi-Fi 模式 | `AT+CWMODE=2`（**纯 SoftAP**） |
| 串口 | 115200 / 8N1 / 无流控 |

> ⚠️ **Wi-Fi 模式必须是 2（纯 AP）**。曾出现 `CWMODE=3`（AP+STA 双模）导致网页完全打不开的回归：固件从不下发 `AT+CWJAP`，STA 侧永远拿不到凭据，ESP 反复去连 flash 里残留的旧 AP，双模下还要同时维护 DHCP 与多个 socket 槽位，最终客户端拿不到 IP。若将来要启用双模，**必须同时实现 `AT+CWJAP` 下发**。

### 5.2 控制协议（V1 ASCII）

采用**可打印 ASCII + 换行分帧**，便于 APK 与串口工具直接调试。不提供加密、鉴权或传输层 CRC。

```text
<TYPE,key=value,key=value,...>\n
```

#### 控制帧：Android → ESP → STM32

```text
<CMD,seq=12,move=F,turn=R,step_speed=60,servo=-15,m2=R>\n
```

| 字段 | 取值 | 含义 |
| --- | --- | --- |
| `seq` | 0–65535 | 16 位序号，用于重复、乱序与丢包检测 |
| `move` | `F`/`R`/`S` | **M1（370）**前进 / 反向 / 停止 |
| `turn` | `L`/`R`/`C` | 左 / 右 / 居中，必须与 `servo` 符号一致 |
| `step_speed` | `60`/`100` | 占空比挡位：100 = 满速挡（95%）、60 = 低速挡（60%） |
| `servo` | −15 ~ +15 | 相对中位角（度），负值左、正值右 |
| `m2` | `F`/`R`/`S` | **M2（N20 唧筒）**活塞推/拉/停，**选填，缺省 = 停止** |

> 📌 `step_speed` 是**历史字段名**。旧步进方案用它选转速档，现改为承载直流电机占空比挡位；字段名与取值范围保持不变以兼容旧客户端。

#### 状态帧：STM32 → ESP / CH340N

```text
<STA,seq=12,link=1,step_rpm=NA,step_est=NA,step_actual=NA,step_on=1,
     servo=-15,roll=1.2,pitch=-2.4,yaw=85.7,m1=F,m2=R,err=0>\n
```

按 `CFG_STATUS_PERIOD_MS`（当前 **200 ms**）周期发送。关键字段语义：

- `link=1` 表示近期收到有效应用命令，**仅代表应用控制链路新鲜，不证明 Wi-Fi 或安卓真实在线**；
- `step_rpm` / `step_est` / `step_actual` 固定为 `NA` —— 本硬件**无编码器**，不做转速反馈；
- `step_on` 恒等于 `(m1 != S)`，表示驱动命令状态，**不证明机械轴实际转动**；
- `roll/pitch/yaw` 读不到或过期时为 `NA`，**不能把 0.0 当作有效测量**。

#### 应答与错误

```text
<ACK,seq=12,result=OK>\n        # 新命令执行成功
<ACK,seq=12,result=DUP>\n       # 幂等重传
<ERR,seq=12,code=E_RANGE>\n     # 参数越界
<ERR,seq=NA,code=E_FORMAT>\n    # 帧格式错误
```

错误码覆盖格式（`E_FORMAT`）、超时（`E_FRAME_TIMEOUT`）、超长（`E_TOO_LONG`）、字段（`E_FIELD`/`E_DUP_FIELD`/`E_MISSING_FIELD`）、越界（`E_RANGE`）、语义（`E_SEMANTIC`）、序号（`E_SEQ_CONFLICT`/`E_SEQ_OLD`/`E_SEQ_AMBIGUOUS`）等类别。

#### 故障位图 `STA.err`

多个故障可同时置位并相加，例如 `err=5` = 链路超时（1）+ IMU 数据超时（4）。

| 位 | 值 | 名称 | 含义 |
| ---: | ---: | --- | --- |
| 0 | 1 | `FAULT_LINK_TIMEOUT` | 有效控制帧超时或接收溢出后的强制断链 |
| 1 | 2 | `FAULT_ESP_RX_LOST` | ESP/USART2 接收缓冲溢出或 ORE 丢字节 |
| 2 | 4 | `FAULT_IMU_DATA_TIMEOUT` | 姿态数据过期/不可用 |
| 3 | 8 | `FAULT_IMU_I2C_RECOVERY_FAILED` | 姿态软件 I²C 总线恢复失败 |
| 4 | 16 | `FAULT_STEPPER_DISABLED` | 配置显式禁用该路电机输出（错误码名沿用旧方案） |
| 5 | 32 | `FAULT_UART_TX_DROPPED` | UART 发送队列丢弃 |
| 7 | 128 | `FAULT_OLED_I2C` | OLED 软件 I²C 运行期异常 |
| 8 | 256 | `FAULT_CONFIGURATION` | 关键配置或定时器初始化不一致 |

> 注意：协议错误用即时 `ERR` 告知；`STA.err` **只描述持续活动的运行期故障**，二者不可混用。

### 5.3 失联与溢出安全策略

**超过 1000 ms 未收到有效命令**时，固件立即：

1. 两路电机全部停止，A/B 两桥**同时进入 coast**（无励磁停止，不保持未知电流）；
2. 舵机按配置回中（默认回中，避免机械卡滞）；
3. `link=0`、置 `BF_FAULT_LINK_TIMEOUT`，主动关闭旧 TCP 连接释放单客户端槽位。

**接收缓冲溢出 / UART ORE** 触发更严格的策略：立即丢弃残余字节、重置解析器、清除会话与序号窗口、停止两路电机、回中舵机 —— **不等待普通的 1 秒保活超时**。

> 💡 安全设计原则：**任何解析、语义或序号失败都不能造成部分电机或舵机动作**。非法帧、语义拒绝帧和旧帧都不能刷新保活。

### 5.4 序号窗口机制

序号窗口是防「命令重复执行」和「乱序覆盖」的核心机制：

| 条件 | 动作 |
| --- | --- |
| 首帧 / 失联后新建会话 | 接受，建立窗口 |
| 序号相同且控制字段完全相同 | 视为**幂等重传**，不重复执行，回 `ACK,DUP` 并刷新保活 |
| 序号相同但载荷不同 | 拒绝，`E_SEQ_CONFLICT` |
| 模 65536 差值 1–32767 | 接受（差值 >1 记录序号缺口） |
| 差值 = 32768 | 回绕歧义，拒绝，`E_SEQ_AMBIGUOUS` |
| 差值 > 32768 | 旧帧/乱序帧，拒绝，`E_SEQ_OLD` |

### 5.5 舵机方向约定

固件在与上位机对接的那一层把角度取反（`angle = -angle`），因此**网页/协议侧只需按「左 = 正、右 = 负」的直觉下发**，最终脉宽方向由固件统一保证。

> ⚠️ **极性反转只允许存在于一层**。本轮修正时发现网页端与固件端各反了一次、相互抵消成「网页左键实际右转」，已把网页端映射改回与固件一致。

安全行程 `±15°` 的换算基准仍是 `CFG_SERVO_FULL_SCALE_DEG = 30`，因此 ±15° 只给出满量程 **1/2** 的脉宽偏移：左 −15° → 1750 µs、右 +15° → 1250 µs、0° → 1500 µs，**不再出现 1000/2000 µs 端点**。

---

## 六、代码架构

### 6.1 分层设计

固件约 **6,000 行 C 代码**，按职责严格分层，`main.c` 只做初始化与主循环调度，业务逻辑不堆放在入口文件。

```text
STM32控制工程/
├── Core/            CubeMX 生成层（时钟、GPIO、TIM、USART 初始化）
│   ├── Inc/  Src/     main.c 仅初始化 + while(1){ App_Process(); }
├── app/          应用层：状态机与调度
│   ├── app.c         主循环调度、命令分发、超时检查
│   └── app_config.h  ★ 全部可调参数的唯一入口
├── bsp/          板级支持层
│   ├── bsp_board.c   板级初始化、紧急 coast
│   ├── bsp_time.c    32 位微秒时基（TIM4 扩展）
│   ├── bsp_uart.c    环形缓冲收发、错误回调
│   └── esp_link.c    ★ ESP-01S AT 状态机
├── control/      控制层
│   ├── motor_control.c  两路 H 桥 IN1/IN2 与占空比
│   ├── servo_control.c  舵机角度→脉宽换算与限幅
│   ├── control_arbiter.c 本地调试按键与远端命令的仲裁
│   └── faults.h         故障位定义
├── drivers/      驱动层
│   ├── soft_i2c.c    软件 I²C（两条独立总线复用）
│   ├── ssd1306.c     OLED 驱动
│   └── jy61p.c       IMU 角度寄存器读取
├── ui/           界面层
│   └── oled_ui.c     单页 ASCII 状态屏
├── protocol/     协议层
│   ├── ascii_protocol.c  V1 ASCII 组帧/解析/校验
│   ├── http_ui.c         内嵌网页控制页（447 行）
│   └── ring_buffer.c     无锁环形缓冲
├── cmake/        工具链与链接脚本
├── scripts/      构建、烧录、串口工具
└── tests/        主机回归测试
```

### 6.2 设计原则

下面五条是本固件在实现中反复兑现的约束，也是代码评审时的检查项。

**① 中断只做搬运，主循环做决策**
UART 中断仅把字节写入固定大小环形缓冲，完整帧解析在主循环完成。中断里不做任何阻塞业务，也不直接驱动执行器。

**② 固定内存，无动态分配**
所有缓冲、字段表、状态槽均为固定大小数组，业务代码不使用 `malloc`。这既保证 RAM 占用可预测（当前 79.92%），也避免碎片化导致的长期运行风险。

**③ 配置集中于单一入口**
所有可调参数集中在 `app_config.h`，并配以**编译期静态校验**。例如：

```c
#if ((CFG_HSE_VALUE_HZ * CFG_PLL_MULTIPLIER) != CFG_SYSCLK_HZ)
#error "HSE 与 PLL 倍频必须严格计算出 CFG_SYSCLK_HZ。"
#endif

#if (CFG_MOTOR_LOW_DUTY_PERCENT > CFG_MOTOR_FULL_DUTY_PERCENT)
#error "CFG_MOTOR_LOW_DUTY_PERCENT 必须在 1..CFG_MOTOR_FULL_DUTY_PERCENT。"
#endif
```

定时器折算、占空比边界、舵机行程一致性全部在**构建期**拦截，不让配置错误退化成运行期静默故障。

**④ 用编译期门禁防止回归**
缓冲区不匹配曾导致「网页静默发不出去」：`HTTP_RESPONSE_BYTES` 为 4096，而传输缓冲 `HTTP_RAW_BYTES` 只有 3584，响应超长一个字节都发不出去，且串口上 `error=OK`、`reset=0`、`uloss` 不涨 —— **整个失败过程完全静默**。

修复方式除了对齐两个缓冲，还加了编译期门禁：

```c
/* esp_link.c —— 今后只要有人再让传输缓冲小于响应缓冲，构建直接失败 */
static char kHttpRawMustFitResponse[
    (HTTP_RAW_BYTES >= HTTP_RESPONSE_BYTES) ? 1 : -1];
```

**⑤ 执行器动作原子化**
任何一帧命令的校验失败都**不能造成部分动作** —— 要么两路电机与舵机全部按新目标更新，要么全部保持原状。这条约束通过「先完整校验、后统一提交」的两阶段实现保证。

### 6.3 主循环调度时序

各任务的执行周期由 `app_config.h` 统一约定，主循环按到期与否依次推进：

```text
App_Process() 每次迭代：
  ├─ 协议解析       收到完整帧即处理（非周期）
  ├─ 命令分发       校验通过后统一提交执行器
  ├─ 失联检查       1000 ms 无有效命令 → 双停 + 回中 + 关 TCP
  ├─ 姿态采样       每 50 ms  读 JY901S 角度寄存器
  ├─ 状态帧发送     每 200 ms 组 STA 帧 → USART2 + USART3
  ├─ OLED 刷新      每 200 ms 推进一帧；未初始化时每 2000 ms 重试
  └─ IMU 诊断输出   每 1000 ms 打印总线电平与采样统计
```

优先级从高到低为：**命令应答（ACK/ERR） > 控制执行 > 状态上报 > 界面刷新**。状态帧是低优先级，串口队列拥塞时不应阻塞控制或挤掉 ACK。

### 6.4 关键模块：`esp_link.c` 的 AT 状态机

ESP-01S 的 AT 通信是本工程最脆弱的一环，处理要点：

- **逐命令配置并等待自身响应**：核查版本、串口、AP 地址后才创建服务，**不用 `ATE0` 的 OK 代替 `CIPSERVER` 成功**；
- **发送三阶段**：先等 `CIPSEND` 的 `>` → 再发送声明的**准确字节数** → 最后等 `SEND OK`；
- **事件队列分离优先级**：`ACK/ERR` 走事件 FIFO，周期 `STA` 只保留**一个可替换的最新状态槽** —— 避免状态帧拥塞挤掉控制应答；
- **拒绝额外控制客户端**：收到 `CONNECT` 记录连接 ID，`CLOSED`/ESP 重启/接收丢失/发送失败都会撤销控制会话并进入失联安全态；
- **不盲目发 `AT+RST` 或 `+++`**：不能确认 ESP 是否仍等待数据时，诊断输出 `reset=1` 表示需要实际复位，观察到 `ready` 后重新初始化。

### 6.5 主机回归测试

固件代码可在 **PC 上编译运行**，不依赖实板即可验证逻辑：

```powershell
python scripts/build.py host --bootstrap --host-cc C:/path/to/native-gcc.exe
```

通过 HAL 桩（`tests/*/stubs/`）替换硬件依赖，覆盖协议解析、电机控制、PWM 折算、传感器与 OLED 等模块，另含**编译期门禁测试**（故意传入非法配置，验证构建确实失败）。

---

## 七、上位机与控制台

### 7.1 Android 控制台

采用 **Kotlin + Jetpack Compose + Material 3**，单 Activity + 导航架构，网络、协议、重连与完整控制目标均在 UI 之外管理。

| 页面 | 主内容 |
| --- | --- |
| **设备** | AP 热点直连常驻卡、系统 Wi-Fi 设置入口、LAN/Mock 发现、连接进度与错误 |
| **控制** | 连接状态、M1 推进与 M2 唧筒独立方向组、±15° 舵机、回传状态、固定底栏双路急停 |
| **状态/调试** | 两路固件方向、兼容 RPM（NA）、舵角、姿态、延迟、最后更新、故障与日志导出 |
| **设置** | 独立 AP/LAN 参数、通信时序、两路反向开关、安全停止与减少动态效果 |

<p align="center">
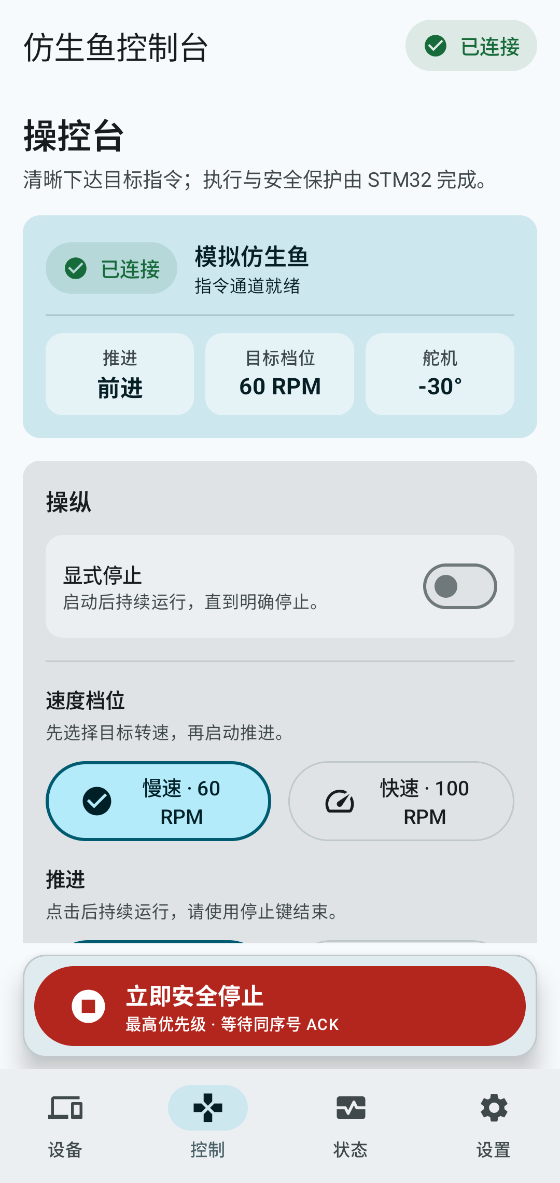
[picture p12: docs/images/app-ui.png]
控制台界面
  
</p>

工程结构：

```text
app/src/main/java/com/bionicfish/controller/
├── transport/   TCP、UDP、Wi-Fi 专用 Socket、Mock
├── protocol/    CMD 编码、STA/ACK/ERR、流式分帧
├── device/      会话、握手、发送队列、安全停止、重连
├── control/     ViewModel 与完整控制目标
├── telemetry/   回传状态、新鲜度、故障位、本地日志
├── settings/    DataStore、AP 参数、用户偏好
└── ui/          Compose 页面、主题、导航、可复用组件
```

**构建配置**：Java 17 / Kotlin 2.3.21 / Gradle 8.13 / AGP 8.13.2，min·target·compile SDK = 26·36·36。

**安全设计**：底部「立即安全停止」始终可达，**不加阻碍紧急停止的二次确认**；导航离开、切后台、断开连接均按策略双停，**重连不恢复旧方向**；网络急停失败必须提示，不能把本地目标当成确认停机。

### 7.2 内嵌网页控制页

ESP-01S 除 TCP 控制端口外，还提供 **HTTP 控制页**：手机连上 `BionicFish-AP` 后，浏览器直接访问 `192.168.4.1:9000` 即可操作，无需安装 APK。

页面经过一轮重做，支持「低速挡」运行时切换与舵机限角。

> ⚠️ 网页与 Android 会**争抢同一个控制客户端槽位**。固件只接受一个控制客户端，网页与 App 同时连接时，后到者会被 `AT+CIPCLOSE`。

### 7.3 硬件与电气设计的成本小结

| 类别 | 主要器件 | 量级 |
| --- | --- | --- |
| 主控与通信 | STM32F103C8T6、ESP-01S、CH340N | ¥30 量级 |
| 驱动与执行 | TB6612FNG、370 减速电机、N20、IP65 舵机 | ¥100 量级 |
| 传感与显示 | JY901S、SSD1306 | ¥60 量级 |
| 电源与保护 | ME6211、LM2596S、XT60、咪头座、5 A 保险丝 | ¥20 量级 |
| 接口与结构 | 拓展板打样、排针排母、32 针母座 | ¥50 量级 |
| 结构 | PETG 耗材、紧固件、密封件 | ¥100 量级 |
| 电源 | 3S 航模锂电、稳压模块 | ¥100 量级 |

**设计取向是「用成熟模组换开发时间」**：ESP-01S 用 AT 固件而非自绘透明桥，IMU 用模块内部解算而非自写滤波，舵机用成品防水件而非自制密封，电源用 LM2596S 量产模块而非自绘 DCDC —— 每一处都选择了「贵一点但少一个失败点」的方案。

> 📌 有一点需要特别说明：**电源与接口上的钱花得非常少**。ME6211 单价约 ¥0.5、LM2596S 模块约 ¥3、XT60 与咪头座合计约 ¥2，全部加起来不过一杯奶茶。真正决定这台机器能不能稳定跑起来的，不是这几块钱的器件，而是**把「可替换、可观测、可保护」当成硬约束写进设计里** —— 这一点与预算无关，只与工程纪律有关。

> 📌 上述为按器件与功能类别的量级估算，**不含具体单价与供应商信息**。完整采购清单归档于项目内部资料，不随公开仓库发布。

---

## 八、仓库结构

```text
仿生鱼工程/
├── README.md                    ← 本文件
├── CHANGELOG.md                 开发日志（按版本/日期记录）
├── docs/
│   ├── images/                  文档配图、实拍照片与演示动图（demo.gif）
│   ├── media/                   演示视频（H.264 MP4，浏览器可在线播放）
│   └── 复刻指南/                  ★ 硬件制造 / 通信调试 / 电控编写
├── 仿生鱼完整项目交付包_v1/      ★ 完整交付包
│   └── 仿生鱼完整项目交付包/
│       ├── STM32控制工程/         固件源码、构建脚本、协议与硬件文档
│       ├── 仿生鱼安卓_v0.5.0_交付包/  Android 源码 + APK + 验证报告
│       └── 交付说明.md
├── 电气设计说明/                  ★ 电源架构、拓展板接口与调试通道
├── 鱼尾装配/                     ★ 尾段结构件开源（零件 + 装配体 + 清单）
└── 实物图片/                     结构件照片
```

> 📌 以下目录**不随仓库发布**，已在 `.gitignore` 中忽略，仅保留本地副本：
> `建模/`（完整 SolidWorks 工作区，含外壳辅助脚本、历史版本、第三方素材）、
> `电子信息方案/`（早期方案原始资料，含 `.epro2` 工程文件、导出图片与 AI 提示词草稿）、
> 讲演素材与参考图。整理后的成果已分别发布为 `鱼尾装配/` 与 `电气设计说明/`。

**入口导航**：

| 我想… | 去哪里 |
| --- | --- |
| **从零复刻一台** | [**`docs/复刻指南/`**](docs/复刻指南/README.md) ← 硬件制造 · 通信调试 · 电控编写 |
| 了解当前固件与硬件边界 | [`STM32控制工程/README.md`](仿生鱼完整项目交付包_v1/仿生鱼完整项目交付包/STM32控制工程/README.md) |
| 编译固件 | [`scripts/BUILDING.md`](仿生鱼完整项目交付包_v1/仿生鱼完整项目交付包/STM32控制工程/scripts/BUILDING.md) |
| 看通信协议细节 | [`通信协议.md`](仿生鱼完整项目交付包_v1/仿生鱼完整项目交付包/STM32控制工程/通信协议.md) |
| 查引脚与驱动 | [`硬件引脚与驱动说明.md`](仿生鱼完整项目交付包_v1/仿生鱼完整项目交付包/STM32控制工程/硬件引脚与驱动说明.md) |
| 查电源架构与电压 | [`电源方案与电压汇总.md`](电气设计说明/电源方案与电压汇总.md) |
| 查拓展板接线与调试通道 | [`拓展板接口与调试通道.md`](电气设计说明/拓展板接口与调试通道.md) |
| 编译/安装 Android 应用 | [`Android工程/README.md`](仿生鱼完整项目交付包_v1/仿生鱼完整项目交付包/仿生鱼安卓_v0.5.0_交付包/Android工程/README.md) |
| 取尾段结构件 | [`鱼尾装配/README.md`](鱼尾装配/README.md) |
| 看验收边界 | [`验收检查清单.md`](仿生鱼完整项目交付包_v1/仿生鱼完整项目交付包/STM32控制工程/验收检查清单.md) |

---

## 九、快速开始

### 9.1 固件构建

在 `STM32控制工程/` 目录：

```powershell
python scripts/build.py firmware --bootstrap     # 编译固件
python scripts/build.py host --bootstrap --host-cc C:/path/to/native-gcc.exe   # 主机测试
```

产物输出至 `build-firmware/`，包含 `.bin`、`.elf`、`.map` 与记录版本/哈希的 `build-info.json`。当前固定 CubeF1 v1.8.6。

> ⚠️ **不要在源码目录直接用 CubeMX 重新生成**，按构建说明在独立目录生成后审核合并 —— 只核对引脚数值就覆盖受维护的 Core 代码会导致回归。
> ℹ️ 构建**只产生文件，不会自动烧录或驱动电机**。

### 9.2 Android 构建

```powershell
./scripts/Build-Apk.ps1 -JdkHome '你的JDK17目录' -AndroidSdk '你的AndroidSDK目录'
./gradlew.bat connectedDebugAndroidTest --no-daemon --no-parallel
```

产物位于 `app/build/outputs/apk/debug/app-debug.apk`。或直接安装交付包中的 `BionicFish-v0.5.0.apk`。

### 9.3 首次通电流程

1. **接线检查**：确认 ESP-01S 使用受支持的 AT 固件、USART2 交叉收发正确、115200-8-N-1、3.3 V 供电充足；检查两条 I²C 总线（PB6/PB7 **需外接 4.7 kΩ 上拉**）。
2. **上电前检查电源**：确认 XT60 极性与电池正负一致（**保险丝不防接反**）；确认 ME6211 逻辑轨输出为 3.3 V、LM2596S 动力轨输出已调到电机/舵机额定电压；确认 5 A 保险丝已装好、未用导线短接。
3. **双通道接入**：SWD 接 ST-Link（烧录/断点），Type-C 接板载 CH340（串口日志），**两根线可同时插**。上电后先在串口里应能看到周期性的状态输出。
4. **串口观察**：通过 USART3 查看 `ESP server=... tcp=... reset=... error=...`。`server=1` 表示服务初始化完成，`tcp=1` 表示有控制客户端。
5. **连接**：手机加入 `BionicFish-AP`（密码 `12345678`），保持该无互联网 Wi-Fi，在 Android 设备页点击「AP 直连」。
6. **握手**：应用发送完整合法的 STOP CMD，收到同序号 ACK 与 `link=1` 的 STA 后才显示已连接。**加入 Wi-Fi 或连上 TCP 本身不等于握手完成。**
7. **台架验证**：先验证 STOP 的 ACK、STA、舵机与姿态，再点击前进做低速连续转动测试。确认台架启停、失联、ESP 复位与供电恢复均正常后，才进入下水环节。
8. **下水运行**：篮筐 / 系绳保护下入水，先在浅水确认密封无渗漏、配重与姿态稳定，再做前进、转向与安全停机测试；异常时立即断电回收。本机已按此流程完成泳池 / 静水实测。

### 9.4 常见故障排查

| 现象 | 排查方向 |
| --- | --- |
| 全板无电、串口无任何输出 | 先查 **5 A 一次性保险丝是否已熔断**（熔断为不可逆，需更换）；再查 XT60 是否插到位、电池是否有电 |
| 上电即烧毁模组 | **极大概率是 XT60 极性接反**。保险丝不防反接，务必用万用表确认极性后再上电 |
| 逻辑轨电压不是 3.3 V | 查 ME6211 输入是否正常、输出电容是否虚焊；该 LDO 压差很小，输入低于约 3.5 V 就会跌出稳压区 |
| 动力轨电压不对 / 电机无力 | 调 LM2596S 电位器到电机额定电压；确认其输入未低于最小工作压差，且未触发限流 |
| 电机一转，IMU/OLED 就异常复位 | **逻辑轨与动力轨未隔离干净**。检查两轨是否共用了一段细走线，或地线回流路径过窄 |
| 电机不转但代码/接线无异常 | **优先查 TB6612 的 STBY** —— 只要 STBY 为低，两个 H 桥输出全部高阻 |
| 有 12 V、STBY 已拉高却带不动负载 | 占空比是否为 100%？见 [3.4 节](#34-一个典型的硬件陷阱为什么满速挡是-95-而不是-100) |
| 屏能显示但 IMU 读不到 | 多为 **PB6/PB7 缺外部 4.7 kΩ 上拉**（`IMU … pu=11` 即为该判据） |
| AP 能加入但网页/TCP 打不开 | 查 `CFG_ESP_WIFI_MODE` 是否为 **2**（纯 AP）；查 `server=` 是否为 1 |
| 姿态显示 `R:--- P:--- Y:---` | 看 USART3 的 `I2CBUS` → `IMUSCAN` → `IMU scl= sda= st= probe=` 三段诊断 |
| App 连上就断、反复重连 | `AT+CIPSTO=3`（3 秒无数据即断开）+ 固件只接受单个控制客户端；**已知未修复项** |
| 烧录报 `failed to erase memory` | 先用 RAM 读写对照实验排除 MCU 内部 flash 控制器故障 |

> 💡 **排查顺序建议**：先看**串口有没有输出**（判断 MCU 是否在跑）→ 再看**两轨电压是否正常**（判断供电）→ 最后才怀疑具体模组。因为有双通道调试，绝大多数问题在两分钟内就能定位到「是哪一层」。

---

## 附：开发历程

项目自 2026 年 5 月启动，经历四个阶段：

| 阶段 | 时间 | 主要工作 |
| --- | --- | --- |
| **方案探索** | 5–6 月 | 项目定位、需求拆解、硬件选型、项目计划书迭代至 v3.2 |
| **机械与通信** | 6–8 月 | 曲柄摇杆机构自主设计、外壳外观建模与分件、STM32 拓展板设计、通信协议定义 |
| **电控收敛** | 9 月 | 推进方案由步进改为直流减速电机、TCP 链路修复、双挡位与舵机限角、网页控制页重做、Android v0.5.0 |
| **实机下水** | 9 月 | 整机装配完成并**实际入水运行**，在泳池 / 静水环境完成密封、配重、姿态与基本机动的下水实测 |

完整记录见 [CHANGELOG.md](CHANGELOG.md)。

---

## 致谢

感谢「自然与设计」课程提供的指导与支持。
感谢维特智能（WitMotion）与乐鑫（Espressif）的公开技术文档。
感谢在项目制作、联调与实机下水验证中承担工作的**组员同学** —— 机械件的加工装配、电气接线与下水现场的回收复盘，都是集体完成的。
感谢在开发全程参与协作的 **AI Agent 助理工具** —— 从方案推演、样板代码、协议解析到日志排错与本文档的词句整理，本项目能在课程周期内打通全栈，离不开这条人机协作链路。

> 💡 如果你正在复刻本项目，欢迎同样把 AI 助理工具纳入你的工作流；但请记住：**工具负责快，人负责对**。所有涉及电气安全与实机行为的结论，都必须由你在真实硬件上验证过才能采信。

## 许可

本项目为课程设计成果。如需引用、复刻或二次开发，请先联系作者。

---

## 写在最后

随着**AI Agent**和各家模型的迅速进步，他们在各领域的出场率越来越高，在项目上的职能占比也日渐扩大。
这使得个人全栈能力及效率大幅提升、项目单人可实现的同时，也影响了初学者针对基础项目能力开发的忽视。
Agent是减少重复劳动的重要工具，但他目前也还是工具，暂时还不能完全替代开发者思考和布局。
希望各位都能找到属于自己的核心能力，在复刻、调试、二次创造的过程里不断沉淀，不断前进。

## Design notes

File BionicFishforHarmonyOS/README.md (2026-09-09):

# 仿生鱼 HarmonyOS 上位机（暂停）

> 2026-09-09：当前交付采用 STM32F103C8T6 + ESP-01S + Android TCP。本目录保留早期 WebSocket/JSON 骨架，暂停开发，不参与当前构建、部署或验收，也不能与当前 ESP-01S 固件直接配套。下文为历史设计记录。

这是一个面向 HarmonyOS 设备的 ArkTS / Stage 模型上位机应用骨架，用于连接 ESP32-S3 WebSocket 网关，实现仿生鱼的实时数据收发、方向控制、参数下发和基础遥测显示。

## 设计目标

| 模块 | 设计 |
|---|---|
| 通信链路 | HarmonyOS App → WiFi AP → `ws://192.168.4.1/ws` → ESP32-S3 → UART → STM32 |
| 控制原则 | App 发送 `throttle`、`yaw`、`pitch`、`mode` 等高层运动意图，不直接下发舵机瞬时角度 |
| UI 风格 | ArkUI 原生组件、组件级毛玻璃、沉浸深色水下光感、连续脉冲动画、大触控面积 |
| 安全逻辑 | 固定急停入口、参数限幅、心跳、周期性控制帧、断连状态提示 |
| 后续扩展 | 通信层集中在 `FishSocketClient.ets`，可替换为 BLE、UDP 或自定义二进制协议 |

## 工程结构

| 路径 | 作用 |
|---|---|
| `AppScope/app.json5` | 应用级配置、包名、图标、应用名 |
| `entry/src/main/module.json5` | HAP 模块配置、入口 Ability、`ohos.permission.INTERNET` 权限 |
| `entry/src/main/ets/entryability/EntryAbility.ets` | Stage 模型 UIAbility 入口 |
| `entry/src/main/ets/pages/Index.ets` | 主控制台页面，包含连接、方向控制、遥测、参数下发 |
| `entry/src/main/ets/model/FishProtocol.ets` | JSON 协议模型、默认参数、限幅和帧构建 |
| `entry/src/main/ets/service/FishSocketClient.ets` | 官方 `@kit.NetworkKit` WebSocket 封装 |

## 默认连接

| 项目 | 值 |
|---|---|
| ESP32 热点 | `BionicFish_ESP32` |
| 默认 IP | `192.168.4.1` |
| WebSocket | `ws://192.168.4.1/ws` |
| 数据格式 | JSON over WebSocket |

## App 发送的数据帧

### 控制帧

```json
{
  "type": "control",
  "seq": 101,
  "mode": "manual",
  "throttle": 60,
  "yaw": 0,
  "pitch": 0,
  "depth_target": 0.3,
  "tail_amp": 45,
  "tail_freq": 1.6,
  "trim": 0,
  "emergency_stop": false,
  "timestamp": 12345678
}
```

### 参数帧

```json
{
  "type": "config",
  "seq": 201,
  "tail_amp_limit": 80,
  "tail_freq_limit": 3.5,
  "servo_trim_tail": 0,
  "servo_trim_left_fin": -2,
  "servo_trim_right_fin": 2,
  "timestamp": 12345678
}
```

### 心跳帧

```json
{
  "type": "heartbeat",
  "seq": 301,
  "timestamp": 12345678
}
```

## ESP32 需要回传的数据帧

```json
{
  "type": "telemetry",
  "seq": 501,
  "battery": 7.4,
  "rssi": -58,
  "mode": "manual",
  "depth": 0.35,
  "roll": 1.2,
  "pitch": -2.8,
  "yaw": 86.5,
  "stm32_online": true,
  "error": 0
}
```

关键指令建议回 ACK：

```json
{
  "type": "ack",
  "seq": 201,
  "ok": true,
  "message": "config applied"
}
```

## 构建与打包 `.hap`

| 步骤 | 操作 |
|---|---|
| 1 | 使用 DevEco Studio 打开 `BionicFishHarmony` 目录 |
| 2 | 安装或选择 HarmonyOS SDK API 12+，建议 HarmonyOS NEXT / API 12 或更高 |
| 3 | 在 `File > Project Structure > Signing Configs` 配置调试签名 |
| 4 | 等待 DevEco 同步 hvigor 工程 |
| 5 | 运行 `Build > Make Module 'entry'` 或 `Build Hap(s)/APP(s) > Build Hap(s)` |
| 6 | 生成的 `.hap` 通常位于 `entry/build/default/outputs/default/entry-default-unsigned.hap` 或对应签名输出目录 |

> 当前工作区没有 DevEco Studio / HarmonyOS SDK 构建链，因此这里提供的是可导入工程源码；实际 `.hap` 需要在安装 SDK 的环境中生成。

## 官方 API 使用点

| 能力 | API |
|---|---|
| Stage 模型入口 | `@kit.AbilityKit` 的 `UIAbility` |
| WebSocket | `@kit.NetworkKit` 的 `webSocket.createWebSocket()`、`connect()`、`send()`、`close()`、`on('open/message/close/error')` |
| 日志 | `@kit.PerformanceAnalysisKit` 的 `hilog` |
| 毛玻璃 | ArkUI 通用属性 `backgroundBlurStyle(BlurStyle.COMPONENT_THICK / COMPONENT_REGULAR)` |
| 动画 | ArkUI `animateTo`、`animation`、`scale`、`opacity` |

## 视觉与交互说明

| 区域 | 行为 |
|---|---|
| 顶栏 | 显示 App 名和固定急停按钮 |
| 连接卡片 | 编辑 WebSocket 地址、连接/断开、显示电池/深度/信号 |
| 模式切换 | 手动、巡航、调试、停止 |
| 方向控制 | 按住方向按钮发送控制量，松手自动回中 |
| 参数面板 | 调整目标深度、摆尾幅度、摆尾频率、舵机微调 |
| 遥测面板 | 显示横滚、俯仰、航向、错误码和 STM32 在线状态 |

## 兼容提醒

| 问题 | 处理 |
|---|---|
| SDK 对 `BlurStyle.COMPONENT_*` 报错 | 改为 `BlurStyle.Thick` / `BlurStyle.Regular`，官方同页文档也支持这些枚举 |
| ESP32 需要 WebSocket 子协议 | 可在 `FishSocketClient.ets` 的 `connect()` 选项中增加 `protocol: 'bionic-fish-json'` |
| 设备连接 ESP32 热点后无法上网 | 正常现象，WiFi AP 模式下手机网络会切到 ESP32 局域网 |
| 控制频率需要调整 | 修改 `FishSocketClient.ets` 中控制循环 `120ms` 和心跳 `1000ms` |

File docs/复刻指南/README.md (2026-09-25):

# 复刻指南

本指南面向想要**从零复刻一台仿生鱼**的读者，按三个方向组织：

| 方向 | 文档 | 你会得到 |
| --- | --- | --- |
| **① 硬件制造** | [硬件制造.md](硬件制造.md) | 采购清单、拓展板与接线、外壳与尾段打印装配、上电前检查 |
| **② 通信调试** | [通信调试.md](通信调试.md) | ESP-01S 刷写与 AT 配置、双通道调试接入、协议联调、故障定位 |
| **③ 电控编写** | [电控编写.md](电控编写.md) | 固件构建与环境、代码结构、如何改参数、如何扩展一个新功能 |

---

## 阅读前提

> ⚠️ **复刻前请先了解本项目的验证状态。** 软件层（固件主机回归、Android 单元/仪器测试）已通过，**整机也已在泳池 / 静水环境完成实际下水运行**（密封、配重、姿态与基本机动已验证）。但下列项目**尚未做过逐项定量标定**，仍需你自己在实物上确认：2 s 慢周期 + 95% 占空比下 370 电机能否稳定带载、堵转电流与 TB6612 温升、N20 唧筒的行程限位接线与动密封的长期可靠性。

**建议的复刻顺序**：

```text
① 硬件制造  ──►  ② 通信调试  ──►  ③ 电控编写
   先让硬件能通电         再让链路能通信        最后按需改固件
   （不必等全部做完）      （串口能看到日志）    （不要一上来就改代码）
```

**关键原则：不要跳步。** 这个项目里最耗时的部分不是写代码，而是**在硬件没通、链路没通的情况下改代码**。先把每一层单独验证过，再往上叠加。

---

## 关于 AI 助理工具：建议怎么用

本项目的开发全程有 AI Agent 参与，也**建议你在复刻时同样把 AI 助理工具纳入工作流** —— 但要用对地方：

| 适合交给工具 | 必须自己来 |
| --- | --- |
| 查数据手册、核对引脚与外设时钟配置 | 电源极性与接线顺序的最终确认 |
| 生成样板代码、改配置常量、搭测试脚手架 | 保险丝规格、限流点等安全参数取舍 |
| 解析串口日志、从 `STA` 与故障位图反推故障层 | 电机带载能力、堵转发热等实机行为判读 |
| 把报错、寄存器值与现象串起来做假设推演 | 防水、配重、下水前的安全检查 |

**为什么这个项目能这么用**：因为硬件上预留了**双通道闭环**（见 [3.5.2 节](../../README.md#352-板载-ch340-的实战价值双接-ai-agent-联合调试)）—— SWD 能烧录、CH340 能读日志，工具才有「改 → 烧 → 看 → 再改」的抓手。**没有可观测性，AI 只能猜；有了可观测性，AI 才能定位。**

> ⚠️ **底线**：工具给出的任何电气结论，都要用万用表／示波器在你的实物上复核后才能采信。AI 的强项是提效，不是替你承担实机风险。

---

## 三条最容易踩的坑（先看这个）

在动手前，请务必知道这三件事 —— 它们都不是数据手册里显著位置的提示，但直接决定复刻能否成功：

### 1. 满速挡必须是 95%，不能是 100%

100% 占空比在 STM32F1 上落成 `CCR = ARR + 1`，PWM 输出**恒为高电平、永不产生下降沿**。TB6612 的 PWM 输入依赖持续开关边沿维持高侧栅极/自举驱动，恒定高电平会让**自举电容无法刷新**，结果是「有 12 V、STBY 已拉高，电机却带不动负载」。

详见 [README 3.4 节](../../README.md#34-一个典型的硬件陷阱为什么满速挡是-95-而不是-100)。

### 2. Wi-Fi 模式必须是 2（纯 AP），不能是 3

`AT+CWMODE=3`（AP+STA 双模）会导致**网页完全打不开**：固件从不下发 `AT+CWJAP`，STA 侧永远拿不到凭据，ESP 反复去连 flash 里的旧 AP，双模下还要同时维护 DHCP 与多个 socket 槽位，最终客户端拿不到 IP。

详见 [README 5.1 节](../../README.md#51-通信链路)。

### 3. 保险丝不防接反

XT60 极性接反会**直接击穿稳压模块与所有模组**。上电前必须用万用表确认极性。

---

## 方向间的依赖关系

```text
┌─────────────────┐
│  ① 硬件制造      │  产出：一台能通电、能上电的裸机
│  采购 · 接线 · 打印 │
└────────┬────────┘
         │ 双通道（SWD + CH340）就位
         ▼
┌─────────────────┐
│  ② 通信调试      │  产出：串口能看到 STA，手机能握手
│  ESP 配置 · 协议  │
└────────┬────────┘
         │ 链路已验证
         ▼
┌─────────────────┐
│  ③ 电控编写      │  产出：按自己需求改造的固件
│  构建 · 结构 · 扩展│
└─────────────────┘
```

**为什么按这个顺序**：② 的每一步都需要 ① 提供可观测的硬件（串口、SWD）；③ 的每次改动都需要 ② 提供可读的日志反馈。反过来做，你会同时面对「代码可能错、硬件可能错、链路可能错」三重不确定，无法定位。

---

## 参考材料索引

| 我想查… | 去哪里 |
| --- | --- |
| 器件选型的理由与取舍 | [README 第三章](../../README.md#三硬件与电气设计) |
| 具体引脚分配 | [README 3.3 节](../../README.md#33-引脚分配) · [硬件引脚与驱动说明.md](../../仿生鱼完整项目交付包_v1/仿生鱼完整项目交付包/STM32控制工程/硬件引脚与驱动说明.md) |
| 电源架构与电压 | [电源方案与电压汇总.md](../../电气设计说明/电源方案与电压汇总.md) |
| 拓展板接线与调试通道 | [拓展板接口与调试通道.md](../../电气设计说明/拓展板接口与调试通道.md) |
| 协议字段与错误码全文 | [通信协议.md](../../仿生鱼完整项目交付包_v1/仿生鱼完整项目交付包/STM32控制工程/通信协议.md) |
| 尾段零件清单 | [鱼尾装配/README.md](../../鱼尾装配/README.md) |
| 构建工具链版本与命令 | [scripts/BUILDING.md](../../仿生鱼完整项目交付包_v1/仿生鱼完整项目交付包/STM32控制工程/scripts/BUILDING.md) |
| 验收判据与实测项 | [验收检查清单.md](../../仿生鱼完整项目交付包_v1/仿生鱼完整项目交付包/STM32控制工程/验收检查清单.md) |
| 开发过程与踩坑记录 | [开发日志与修改清单.md](../../仿生鱼完整项目交付包_v1/仿生鱼完整项目交付包/STM32控制工程/开发日志与修改清单.md) |

---

_本指南随 V1.0.0 发布。若你在复刻中发现了本文档未覆盖的问题，欢迎反馈。_

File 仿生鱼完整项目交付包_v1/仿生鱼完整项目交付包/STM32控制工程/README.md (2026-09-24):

# STM32 仿生鱼控制工程

当前交付：STM32F103C8T6 + ESP-01S AT/TCP + Android V1 ASCII 控制器。**两路直流减速电机**（M1 = 370 主推进、M2 = N20 唧筒）分别由 TB6612 的 A/B 两个 H 桥驱动，各自独立启停与换向；步进方案已作废。**V1.0.0 起 N20 唧筒已实装并可由协议 `m2=` 字段正确调用**。HarmonyOS、ESP32 WebSocket、自定义 ESP 透明桥均不在本轮链路中。

## 硬件和软件边界

| 功能 | 配置 |
| --- | --- |
| MCU / 时钟 | STM32F103C8T6，64 KiB Flash、20 KiB RAM；HSE 8 MHz、SYSCLK 72 MHz，晶振需与实板一致 |
| 推进电机 | **两路直流减速电机**：M1 = 370（TB6612 A 桥，PA0/PB12/PB13）、M2 = N20 12V 版**唧筒电机**（B 桥，PA1/PB14/PB15）。TIM2 **2 s 慢周期载波**，满速挡 **95%** / 低速挡 **60%**；无编码器、无闭速、无位置控制 |
| 舵机 | PA6 / TIM3 CH1，50 Hz，1000–2000 µs，默认中位 1500 µs；安全行程 **±15°**（±15° 只给出满量程 1/2 的脉宽偏移 → 1250/1750 µs） |
| ESP 通信 | PA2 TX → ESP RX，PA3 RX ← ESP TX；115200 / 8N1，无 RTS/CTS |
| 调试 | PB10 USART3 TX → CH340 RX；仅输出诊断及 V1 帧，不接收控制命令 |
| 姿态 | JY61P，PB6/PB7 软件 I²C；地址 0x50、起始寄存器 0x3D 为待实板核实的配置 |
| 屏幕 | SSD1306 128×64，PB8/PB9；尝试 0x3C/0x3D；保留原单页 ASCII 布局 |
| 未使用接口 | KEY1/2/3、PA7 第二舵机、PA9/PA10 USART1 未启用；不据此判断物理悬空 |

### 板级与调试通道

固件运行在**自研拓展板**上：核心板以 **32 针母座**插接，UART 与电机、舵机接口全部**排针扇出**，TB6612 / ESP-01S / JY901S / OLED 均可拔换。设计取向沿用 TI 杯电子设计竞赛的模组化范式 —— 故障应通过**拔换模组**定位，而非在板上飞线。

| 调试通道 | 物理接口 | 引脚 | 用途 |
| --- | --- | --- | --- |
| SWD | ST-Link | `PA13` / `PA14` | 烧录、断点、halt 查寄存器 |
| 串口 | 板载 CH340 + Type-C | `USART3`（`PB10` / `PB11`） | 运行期日志与 V1 状态帧，只发不收 |

两条通道**物理独立、可同时接入同一台主机**，因此「改代码 → 烧录 → 读日志 → 再改」可以形成闭环，这也是 AI Agent 联合调试能够落地的前提。协议刻意选择可打印 ASCII + 换行分帧（见 `通信协议.md`），就是为了让串口输出可被工具直接解析，无需额外解码。

**电源**：`XT60 / 咪头 → 5 A 一次性保险丝 → LM2596S (DCDC) → {动力轨：TB6612 VM、舵机；5 V 中间轨 → ME6211 (LDO) → 3.3 V 逻辑轨}`。逻辑轨与动力轨分离，避免电机启停的电流冲击污染 JY901S 与 MCU。保险丝**不防接反**，上电前须确认极性。

所有可调参数在 `app/Inc/app_config.h`。两路电机共用同一挡位（`CFG_MOTOR_FULL_DUTY_PERCENT` / `CFG_MOTOR_LOW_DUTY_PERCENT`，当前 95% / 60%），运行时可经网页「低速挡」开关或协议 `step_speed=60` 切换；各自还有独立使能开关（`CFG_MOTOR_A/B_ENABLED`，当前均为 1），STOP 或失联时两桥 coast。已删除每转步数、RPM 换算、换相表和硬件参数确认门禁；直流电机不需要换相节拍，启停与换向只由 IN1/IN2 决定。`CFG_MOTOR_A_ENABLED=0` 可单独禁用主推进。

**为什么满速挡是 95% 而不是 100%**：2026-09-23 台架排查「有 12 V、STBY 已拉高却带不动负载」时发现，100% 会让 CCR > ARR、PWM 输出恒定高电平、**永不产生下降沿**；TB6612 的 PWM 输入需要持续的开关边沿来维持高侧栅极/自举驱动。改用 95% 后每个 2 s 周期都有一次完整低电平沿，同时 95% × 12 V = 11.4 V，转速与扭矩几乎无损。若实测证明恒高亦可稳定工作，可把该宏改回 100。

`step_rpm` 是历史字段名，现在承载**占空比挡位**：`100` = 满速挡、`60` = 低速挡，仍只接受这两个值。100% 是"满压运行"而不是恒流或过流保护：TB6612 没有过流保护，实板温升与堵转电流必须实测。

没有转速编码器或舵角反馈。`step_rpm`、`step_est`、`step_actual` 均为 `NA`；`step_on=0/1` 表示驱动命令为停止/运行，不证明电机实际转动。JY61P 无效/过期数据上报 `NA`；相邻样本变化筛选默认 90°/50ms，为宽松可配置初值。

## ESP-01S 固件要求

已收到用户提供的 `AT+GMR` 回包：**AT 1.7.4.0，SDK 3.0.5-dev(52383f9)，编译于2020-08-28**，匹配本工程 NONOS 分支，保留现有固件。最初查询启用了 RTS，提供保存修正命令后，用户复查得到 `+UART_CUR:115273,8,1,0,0`，当前串口参数已匹配约 115200、8N1、无流控要求。完整回包与 `UART_DEF` 操作见[硬件说明](硬件引脚与驱动说明.md)。STM32/TCP 实板联调尚待验证，Flash 容量仅在需要重刷时进一步核对。

`bsp/Src/esp_link.c` 使用普通 AT 收发模式，**不能与裸 UART 透明桥一起使用**。GMR 区分 NONOS AT 1.7.4/1.7.5 与 ESP-AT 2.x 命令差异；现场必须核对实际 GMR 结果、Flash 容量及 AT UART 的 GPIO 映射。

ESP-01S 常见容量为 1 MB。不能把面向更大 Flash 或不同 AT 引脚的 ESP8266 通用镜像直接视为兼容镜像。可参考官方 [NONOS SDK v3.0.4 的 AT/Nano 发布说明](https://github.com/espressif/ESP8266_NONOS_SDK/releases/tag/v3.0.4)，选择与真实容量和引脚匹配的固件；未在实物上验证前不把镜像标为已验收。

默认参数与 Android AP 预置相同：

| 项目 | 默认值 |
| --- | --- |
| SSID / 密码 | `BionicFish-AP` / `12345678` |
| AP / 网关 | `192.168.4.1` |
| 掩码 | `255.255.255.0` |
| 传输 | TCP server，端口 `9000`，单控制客户端 |

固件逐命令配置并等待自身响应，核查版本、串口和 AP 地址后创建服务，并完成固定 3 秒 TCP 空闲超时配置；不会用 ATE0 的 OK 代替 CIPSERVER 成功。收到 CONNECT 后记录连接 ID，拒绝额外控制客户端；CLOSED、ESP 重启、接收丢失或发送失败会撤销控制会话并进入失联安全态。

发送先等 CIPSEND 的 `>`，再发送声明的准确字节数，最后等 SEND OK。ACK/ERR 走事件 FIFO，STA 只有一个可替换的最新状态槽。不能确认 ESP 是否仍等待数据时，不把 AT+RST 或 +++ 盲发成载荷：诊断出现 `reset=1` 表示需要实际复位 ESP，观察到 `ready` 后重新初始化。详细兼容条件和异常回归见 `tests/esp_link/README.md`。

## 构建、烧录与验证

唯一固件源列表为 CMake，固定依赖及跨平台用法见 [scripts/BUILDING.md](scripts/BUILDING.md)。Windows 首次构建：

```powershell
python scripts/build.py firmware --bootstrap
python scripts/build.py host --bootstrap --host-cc C:/path/to/native-gcc.exe
```

输出 `build-firmware/bionic_fish.elf`、`.bin`、`.map` 和 `build-info.json`。本轮已用独立目录 `build-fw-v05/` 重做 Arm 交叉构建，产物哈希见下文「验收边界」。主机编译器用于 host 测试，Arm 编译器用于固件，不能相互替代。

ST-LINK 使用 PA13/PA14 和 GND。烧录脚本与手动步骤见 [scripts/README.md](scripts/README.md)。构建不会自动烧录。CubeMX 必须在独立目录生成后审核合并；不能只核对引脚数值就覆盖受维护的 Core 代码。

## 首次连接

1. 完成 USART2 交叉收发、ESP EN/供电、两条 I²C 外部 3.3V 上拉的检查。
2. 启动后在 USART3 观察 `ESP server=... tcp=... reset=... error=...`。`server=1` 表示已完成服务初始化，`tcp=1` 表示有控制客户端；它们不同于应用 CMD 保活。
3. 手机连接上述 AP 并保持无互联网 Wi-Fi，Android 设备页点击“AP 直连”。应用将 TCP Socket 绑定到 Wi-Fi，不需要通过关闭所有蜂窝数据解决路由。
4. 握手发送完整合法的 STOP CMD，收到同序号 ACK 与 `link=1` 的 STA 后才显示已连接。
5. 点击前进验证两路电机按预期转动（M2 唧筒需在页面上单独点「推/拉」键），再验证停止、舵机、姿态和失联停机。`step_speed=60/100` 为历史字段名，现承载占空比挡位（60 = 低速挡、100 = 满速挡）。

## 运行与故障排查

- `LNK`/`STA.link` 表示有效 CMD/幂等重传保活，不证明对端应用身份。正常保活不得打断已下达的电机方向。
- 1000 ms 无有效命令时停止两路电机、默认舵机回中、清除序号窗口并主动关闭旧 TCP，释放控制客户端槽位。UART 丢字节、TCP 断开和发送故障更早触发同一套停止处理。
- OLED 启动不再进行近一秒忙等。未初始化时后台轮流尝试两个地址；整组初始化在 M1 停止时执行。运行期 IC 错误使屏幕失效，停止后重新初始化。最后一行的静态标题 `ASTRA STATIC UI` 已删除（它不携带任何状态，却占掉 8 px 字体空间），因此当前只用 y=0/10/20/32/44 五行，y=56 空出备用。
- PC13 正常每 500 ms 翻转；OLED 未初始化时每 120 ms 翻转。完整亮灭周期分别约 1 s / 240 ms。`I2CSCAN` 分步报告屏幕总线（PB8/PB9）应答地址，`IMUSCAN` 分步报告 JY61P 总线（PB6/PB7）应答地址；`none` 表示当轮扫描未发现应答，不能单凭它断言哪根线错误。两条总线互相独立，一次 `IMUSCAN none` 不代表屏幕总线也有问题。
- JY61P 读不到、屏上 `R:--- P:--- Y:---` 且 `E:` 含 `004`/`00C` 位时，按顺序看 USART3 的三类输出：先看上电一次的 `I2CBUS oled scl= sda= imu scl= sda=`，再看分步的 `IMUSCAN`，最后看每秒一次的 `IMU scl= sda= st= probe= fail= n= e= raw=`。判据表与已测实板现象见 [硬件引脚与驱动说明.md](硬件引脚与驱动说明.md) §4.1/§4.2。
- 实物陀螺仪是 **JY901S**，不是 JY61P。两者 I²C 地址、角度寄存器、读法、上拉要求完全相同，固件无需改动；差异在 Yaw 语义（JY901S 为磁力计绝对航向）与 I²C 走线必须压到约 10 cm 以内，见 [硬件引脚与驱动说明.md](硬件引脚与驱动说明.md) §4.3。
- **PB6/PB7 没有外部上拉电阻**（2026-09-10 实测定论，见同文件 §4.2）。`IMU scl=0 sda=0 pu=11` 表示线路上没有东西在拉低，低电平只是高阻线路被主机驱动过一次后"记住"的。**临时**可用 `CFG_JY61P_INTERNAL_PULLUP=1`（当前默认）走内部 40 kΩ 上拉的台架兼容模式；实测已跑通，读回 `R=4.6 P=-1.0 Y=49.7` 且 `e=0`。**焊上 PB6、PB7 各一只 4.7 kΩ 到 3.3 V 后应改回 0**——40 kΩ 边沿慢、抗 EMI 差，不能带电机下水。若 `pu` 含 0 则是有器件或短路在拉低，另作排查。
- OLED `E:` 是低 12 位十六进制；STA `err=` 是十进制故障位图，详见 [通信协议.md](通信协议.md)。
- AP 能加入但 TCP 失败：先看 `server`、AT 版本/错误及端口。TCP 已连接但 ACK/STA 验证失败：看 `tcp`、USART2 数据、帧尾及发送错误，并确认安装支持 `step_on` 和 RPM 为 `NA` 的新版 APK。
- `reset=1`：按诊断先解决串口/固件或供电问题，再实际复位 ESP；不能依赖未知发送模式下的“自动逃逸”。
- 远端链路排障计数器：`ESP … etx=ok/try stx=ok/try sf= st=` 分开统计 ACK/ERR 与周期 STA 的 CIPSEND 事务。`stx` 的 ok 与 try 同步增长说明 ESP 已确认发出 STA，问题在其后的链路；try 涨而 ok 不涨说明 ESP 拒收或发送失败；`stx` 完全不涨说明固件没尝试下发 STA。
- **调试模式（板载按键）**：`K1`(PB0) 按一次启动 M1、再按一次停止；`K2`(PB1) 舵机左转 −15°；`K3`(PA8) 舵机右转 +15°（安全行程已由 ±30° → ±20° → ±15°）。用于上位机不可用时在台架上验证执行器，每次动作在 USART3 打一行 `DEBUG `；日志按**调用后的真实状态**记录，因此驱动被禁用时不会谎报 ON。**没有任何按键能控制 M2**——这是实体侧已知的功能缺口。
## 验收边界

详见 [验收检查清单.md](验收检查清单.md)。本轮 host 侧通过 **16/16** 测试（含编译期门禁），Arm 交叉构建已重做并成功。

**下列 BIN 尺寸与 SHA-256 属于「2 s 慢周期 + 95%/60% 双挡位 + 舵机 ±15° + CWMODE 回归修复 + HTTP 缓冲修复」版本的 Arm 交叉构建产物**（`build-fw-http/`）：

| 产物 | 字节数 | SHA-256 |
| --- | ---: | --- |
| `bionic_fish.bin` | 34,272 | `2559592197244234f67009fd26682a8785665dbe6f5fa6f692f3113653029e4a` |

占用：Flash **52.29%**（34,272 / 65,536 B）、RAM **79.92%**（16,368 / 20,480 B）。详细记录见 `build-fw-http/build-info.json`，链接告警及本机工具来源边界见构建说明。业务代码使用固定缓冲，无显式动态分配；不对 newlib 内部路径作未经实测的零堆承诺。

> 更早的两版（`build-fw-v05/` `517de91e…`、`build-fw-fix/` `333e4a52…`）分别存在 **CWMODE 回归**与 **HTTP 缓冲不足**，均已被本版取代。

### HTTP 响应缓冲不足修复（2026-09-23，网页打不开的直接原因）

**症状**：CWMODE 修好之后，手机连上 AP、`server=1` 表示 9000 端口在监听，但 **HTTP 页面依然打不开**。

**根因**：两个缓冲区尺寸对不上。

| 缓冲区 | 位置 | 大小 |
| --- | --- | ---: |
| `response[]`（HTTP_RESPONSE_BYTES） | `app/Src/app.c:507` | 4096 |
| `L.raw[]`（HTTP_RAW_BYTES） | `bsp/Src/esp_link.c` | **3584** ← 少了 512 |

v0.5 重做网页后，`kPage` 涨到 **3652** 字节（从 ELF 符号表 `0x0e44` 读出），加上 123 字节响应头与 4 位 Content-Length，**实际响应总长 3779 字节** > `L.raw` 的 3584。

于是 `EspLink_SendRaw` 的守卫 `length > sizeof(L.raw)` 成立，**直接 `return false`** —— 响应一个字节都发不出去，浏览器只能一直超时。**整个失败过程是静默的**：串口上 `error` 仍是 `OK`、`reset=0`、`uloss` 不涨，`tcp` 也会因为客户端超时退出而回到 0，没有任何一处提示"缓冲区装不下"。

**修复**：
1. `HTTP_RAW_BYTES` **3584 → 4096**，与 `HTTP_RESPONSE_BYTES` 对齐；
2. 在 `esp_link.c` 加编译期门禁 `kHttpRawMustFitResponse`，并在该文件 include `http_ui.h` 取常量。**今后只要有人再让传输缓冲小于响应缓冲，构建直接失败**（实测把 `HTTP_RAW_BYTES` 改成 2048 会报 `size of array 'kHttpRawMustFitResponse' is negative`），不会再退化成运行期静默丢包。

**验证**：`L` 结构在 .bss 中由 `0x14d4`(5332) 增到 `0x16d4`(5844)，正好 +512 字节；Arm 构建成功；host 测试 **10/10** 通过；烧录后独立回读 34,272 字节 SHA-256 一致。

### 已知待改进：App 端连上就断（未修复）

安卓端连接成功后会出现「断连—自动重连」反复循环。代码层已定位到两个成因，**本轮未改动**：

1. **`AT+CIPSTO=3`**（`bsp/Src/esp_link.c:494`）：ESP 服务端 **3 秒收不到任何数据就主动断开客户端**。而 App 在 `desired == null` 时只 `delay` 不发帧（`DefaultBionicFishRepository.kt:674-676`），切后台/进设置页/安全停车后一旦出现 3 秒空窗就被单方面断开。注意该值在旧版同样是 3，**非本次回归**，是一直埋着的隐患。
2. **固件只接受一个控制客户端**（`bsp/Src/esp_link.c:250`，`L.client < 0` 才接受）：安卓与网页同时连、或重连时旧连接尚未被 ESP 回收，新连接会被立刻 `AT+CIPCLOSE`。

建议方向：放宽 `CIPSTO`（如 30 s），或让 App 在无命令时也发心跳。

### Wi-Fi 模式回归修复（2026-09-23）

**症状**：手机连上 `BionicFish-AP` 后，IP 直连网页控制页 `192.168.4.1:9000` 完全打不开。

**根因**：`CFG_ESP_WIFI_MODE` 在 v0.5 引入时写成 `3`（AP+STA 双模），但固件**从不下发 `AT+CWJAP`**，STA 侧永远拿不到凭据。ESP-01S 于是反复去连 flash 里残留的旧 AP，落成 `sta=0.0.0.0`；双模下模块还要同时维护 AP 的 DHCP 服务器与多个 socket 槽位，最终导致客户端拿不到 IP、AP 转发失效。

**跨提交对比**（这是定位回归的决定性证据）：

| | 旧版 `9b97230`（可用） | v0.5 `f30f511`（故障） |
| --- | --- | --- |
| `SET_MODE` 下发 | `AT+CWMODE=2`（**写死纯 AP**） | 实参 `CFG_ESP_WIFI_MODE` = **3** |
| `CFG_ESP_WIFI_MODE` | **不存在** | 新增，默认 `3U` |
| `AT+CWJAP` | 无 | **仍然无** ⇒ 配置自相矛盾 |

**修复**：`app/Inc/app_config.h` 的 `CFG_ESP_WIFI_MODE` 由 `3U` 改为 **`2U`**（纯 AP），回到旧版写死的行为。同时 `tests/esp_link/esp_link_host_test.c` 里写死的 `"AT+CWMODE=3"` 改为引用该宏，避免下次改配置时把「配置变更」误报成「功能回归」。

**验证**：Arm 反汇编确认 `8001c12: movs r3, #2`（旧固件同址为 `#3`）；host 侧 **10/10** 全部通过；实板烧录后独立回读 34,272 字节，SHA-256 与本地产物完全一致；USART3 连续观测 `server=1`、`error=OK`、`reset=0`、`uloss=38`（冻结不增长）。

> ⚠️ **副作用**：`3U → 2U` 会让 STA 侧功能彻底消失。当前只需要 AP 直连，符合需求；若将来要启用 STA，**必须同时实现 `AT+CWJAP` 下发**，否则 `3U` 永远是坏配置。

### 已知待改进：App 端连上就断（未修复）

安卓端连接成功后会出现「断连—自动重连」反复循环。代码层已定位到两个成因，**本轮未改动**：

1. **`AT+CIPSTO=3`**（`bsp/Src/esp_link.c:494`）：ESP 服务端 **3 秒收不到任何数据就主动断开客户端**。而 App 在 `desired == null` 时只 `delay` 不发帧（`DefaultBionicFishRepository.kt:674-676`），切后台/进设置页/安全停车后一旦出现 3 秒空窗就被单方面断开。注意该值在旧版同样是 3，**非本次回归**，是一直埋着的隐患。
2. **固件只接受一个控制客户端**（`bsp/Src/esp_link.c:250`，`L.client < 0` 才接受）：安卓与网页同时连、或重连时旧连接尚未被 ESP 回收，新连接会被立刻 `AT+CIPCLOSE`。

建议方向：放宽 `CIPSTO`（如 30 s），或让 App 在无命令时也发心跳。

### 硬件注意：烧录失败可能是 MCU flash 故障

本轮遇到过 `Error: failed to erase memory` / `failed to download Sector[0]` 的烧录失败。用对照实验定位：**写读 RAM `0x20000000` 全部成功，而 flash `0x08000000` 连 4 字节都读不出**，且 RDP/WRP 均无保护、换 5 组 SWD 频率/3 种复位模式/2 个 CubeProgrammer 版本结果相同。RAM 与 flash 挂在同一条总线上，RAM 可用而 flash 全废 ⇒ 指向 **MCU 内部 flash 控制器故障**。更换同型号芯片后立即恢复正常。

**排查顺序**：① 换一块同型号板交叉验证 ② 若换板仍失败再查工具链 ③ 核对 `-ob displ` 全文的 `nBOOT`/`BOOT0` 相关位。

实板验收仍在进行，尤其是两路电机的转向/电流/温升、**2 s 慢周期 + 95% 占空比下 TB6612 能否稳定驱动**、堵转保护、TB6612 无过流保护这一硬缺口、JY61P 寄存器、OLED 热恢复。**N20 唧筒链路已在 V1.0.0 实装并经协议 `m2=` 字段正确调用**，其 12V 额定与行程限位（微动开关）仍建议在整机联调时复核。

本状态页是自写固定内存实现；没有复制或链接上游 Astra，详见 `third_party/oled-ui-astra.UPSTREAM.md`。本轮不做 Astra 移植、分页或按键交互。

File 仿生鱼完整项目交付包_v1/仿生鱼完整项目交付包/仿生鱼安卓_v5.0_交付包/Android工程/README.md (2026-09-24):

# 仿生鱼安卓控制器 v0.5.0

版本：`0.5.0 / versionCode 7`；包名：`com.bionicfish.controller`。本版在 v0.4.0 的独立副本中实现双直流电机与 ±15° 舵机控制，未覆盖旧工程。

用户已在本轮明确授权实施及默认允许两路反转；[原始改造方案](docs/原始资料/双电机控制与舵机15度_安卓端改造方案_v0.5.0.md) 中“只出方案”的旧范围已由该授权覆盖。原文关于固件和实测的描述是用户资料，不是本次硬件测试结论。

## 1. 本版功能与边界

- M1 为 370 直流减速电机（尾段推进），M2 为 N20 直流减速电机（驱动唧筒活塞实现沉浮）；两路各自推/拉/停（推进侧对应前进/停止/后退）。
- 每条 CMD 是两路电机和舵机的完整目标。单路停止只停该路；底部“立即安全停止”显式同时停止两路。
- 舵机预设及滑杆为 -15° / 0° / +15°，1° 步进；发送协议模型拒绝越界值。
- 旧资料曾称配套固件两路均为固定 100% 占空比。现固件为 **2 s 慢周期 + 95%/60% 双挡位**，APK 侧发送 `step_speed=60` 切换低速挡、`100` 切换满速挡；不提供连续 PWM 或 RPM 调速。
- 回传 `m1/m2` 为固件下达方向，不是实测机械反馈。旧固件缺字段显示“未知”；全部转速 `NA` 保持未知。
- 新安装默认允许两路反向；升级时保留旧版明确关闭的设置。在“设置”中开启“允许电机反向”并保存即可。保存关闭反向前先执行双路停止。
- 已移除旧步进参数确认对控制按钮的阻挡，保留旧状态字段和旧故障位解释；旧固件拒绝命令时仍显示真实 ERR。

只修改 Android；没有改写或烧录 STM32、ESP 固件。V1.0.0 已确认双电机（含 N20 唧筒）、±15° 及网页限角配套固件实装；本 APK 不能替其它客户端收窄固件/网页的行程。

## 2. 连接与安装

实际硬件入口是 **Wi-Fi TCP AP 直连**。手机手工加入 `BionicFish-AP`（指引初始密码 `12345678`）后，返回应用连接 `192.168.4.1:9000`。参数来自用户《AP直连_安卓端修改指引.md》，不是本机实测；已修改时以设备实际值为准。

AP Socket 绑定符合目标本地子网的 Wi-Fi，不回退移动数据/VPN；不要求热点有互联网，不自动加入热点或读取 SSID。普通 LAN TCP、UDP 和 Mock 保留，LAN/UDP 地址与发现参数须自行确认。ESP-01S 没有蓝牙，本版不提供可用蓝牙连接。

安装桌面的 `BionicFish-v0.5.0.apk`；交付包根目录也放有同字节的同名副本。不要安装工程 ZIP、AndroidTest APK 或 MCU BIN。完整文件名应以 `.apk` 结尾。S24 安装、来源权限及实际热点行为待实测。

交付采用 debug 签名；覆盖安装要求与手机旧包签名相同。签名冲突时先保存需要的日志/设置，由用户决定是否卸载旧版，不能保证任意历史 APK 可原位升级。

## 3. 工程结构与构建

```text
app/src/main/java/com/bionicfish/controller/
├─ transport/   TCP、UDP、Wi-Fi 专用 Socket、Mock
├─ protocol/    CMD 编码、STA/ACK/ERR、流式分帧
├─ device/      会话、握手、发送队列、安全停止、重连
├─ control/     ViewModel 与完整控制目标
├─ telemetry/   回传状态、新鲜度、故障位、本地日志
├─ settings/    DataStore、AP 参数、用户偏好
└─ ui/          Compose 页面、主题、导航、可复用组件
app/src/test/、app/src/androidTest/   自动测试
scripts/Build-Apk.ps1                分阶段测试、构建、签名校验
```

| 构建项 | 固定配置 |
| --- | --- |
| Java / Kotlin / Gradle | Java 17 / Kotlin 2.3.21 / Gradle 8.13 |
| Android Gradle Plugin | 8.13.2 |
| min / target / compile SDK | 26 / 36 / 36 |
| Build Tools | 36.0.0 |

准备 JDK 17、SDK 36 和 Build Tools 36.0.0，在项目目录执行（实际路径自行填写）：

```powershell
./scripts/Build-Apk.ps1 -JdkHome '你的JDK17目录' -AndroidSdk '你的AndroidSDK目录'
./gradlew.bat connectedDebugAndroidTest --no-daemon --no-parallel
```

第二条需要模拟器或明确选择的测试手机。构建 APK 位于 `app/build/outputs/apk/debug/app-debug.apk`。依赖版本沿用 v0.4.0；本版不新增 release 密钥或发布配置。

## 4. 验证与联调

本次编译、lint、JVM/UI 测试数量、截图、APK 大小、SHA-256 与签名以 [v0.5.0 构建验证结果](artifacts/v0.5.0构建验证结果.md) 为唯一结果来源，不沿用旧版统计。

先用 Mock 验证两路独立方向、舵机 ±15°、双路急停和状态；再在受控台架按 [验收检查清单](验收检查清单.md) 联调。三星 S24、真实 ESP/STM32、机械转向与失联停机时间均未在本轮实测。关闭网络后停止帧可能无法送达，必须依赖固件失联停机及可立即断电措施。

日志仅在本地有界保存，用户主动导出；无默认上传。TCP 协议无加密或设备身份认证，不应暴露到不可信互联网。

详见 [通信协议](通信协议.md)、[UI设计与交互说明](UI设计与交互说明.md)、[AP直连使用说明](docs/AP直连使用说明.md)。

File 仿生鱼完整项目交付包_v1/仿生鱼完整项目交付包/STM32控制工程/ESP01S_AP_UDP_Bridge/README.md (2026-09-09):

# 已停用：自定义透明桥方案

本轮交付只支持 **Android → TCP → ESP-01S AT 固件 → USART2 → STM32**。

原说明中“刷自定义桥后 STM32 不需要改动”的说法错误：当前 STM32 的 `esp_link.c` 使用 AT 指令及 `+IPD`，与裸 UART 透明桥不兼容。不要按旧说明烧录本目录的历史代码。

两份历史 sketch 已移到 `../legacy/ESP01S_AP_UDP_Bridge/` 和 `../legacy/ESP01S_TCP_Transparent_Bridge/`，各自独立目录，避免 Arduino 合并两个 `setup/loop`。这些文件仅作为历史参考，不参与构建或本轮验收，也不代表已完成实板测试。

当前连接、构建及验收入口见上一级 `README.md`。AP 直连默认热点 `BionicFish-AP`，地址 `192.168.4.1`，TCP 端口 `9000`；ESP 固件版本及引脚/Flash 适配要求以该说明为准。

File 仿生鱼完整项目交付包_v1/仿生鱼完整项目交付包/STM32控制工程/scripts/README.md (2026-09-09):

# STM32 烧录脚本

脚本位置：`STM32控制工程/scripts/flash_stm32.ps1`

## 首次准备

1. 安装 ST 的 **STM32CubeProgrammer**（包含 `STM32_Programmer_CLI.exe`）和 ST-LINK USB 驱动。
2. 用 SWD 连接目标板：`SWDIO→PA13`、`SWCLK→PA14`、`GND→GND`，并给 MCU 提供 3.3 V 逻辑电源。
3. 执行 `python scripts/build.py firmware --bootstrap`，生成 `build-firmware\bionic_fish.bin` 与 `.elf`。完整依赖、跨平台命令和 CubeMX 独立目录生成/合并政策见 [BUILDING.md](BUILDING.md)。

## 一键烧录

在本目录（`STM32控制工程`）打开 PowerShell：

```powershell
Set-ExecutionPolicy -Scope Process Bypass
.\scripts\flash_stm32.ps1
```

也可以显式指定固件和烧录器路径：

```powershell
.\scripts\flash_stm32.ps1 `
  -Firmware .\build-firmware\bionic_fish.bin `
  -Programmer 'C:\Program Files\STMicroelectronics\STM32Cube\STM32CubeProgrammer\bin\STM32_Programmer_CLI.exe'
```

BIN 写入 `0x08000000`，ELF/HEX 使用文件中的加载地址；随后执行校验（`-v`），最后复位运行（`-rst`）。`-NoReset` 仅省略最后的复位运行，不会持续拉低 NRST。

默认使用 `mode=NORMAL reset=SWrst freq=4000`，适用于文档中的基本 SWD 接线。只有需要复位下连接且已将 ST-LINK NRST 接到目标 NRST 时，才使用 `-UnderReset`；它选择 `mode=UR reset=HWrst`。硬件复位对 NRST 的要求及 `freq` 参数见 [ST 官方 CLI 说明](https://www.st.com/resource/en/user_manual/um2237-stm32cubeprogrammer-software-description-stmicroelectronics.pdf)。

> 首次上电调试时请先断开步进电机电源，仅给 MCU 供电；工程默认允许前进，采用 10% PWM 固定低速；STOP 和失联会停止输出。首次烧录后先完成通信握手，再进行电机试转。

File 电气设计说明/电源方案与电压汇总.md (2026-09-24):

# 电源方案与电压汇总

> 本文件整理自项目早期的电源设计文档（`仿生鱼项目 – 硬件电压汇总与电源方案设计.docx`，v1.3）与后期实装方案。
> **两套方案存在阶段差异，请以「当前实装」一节为准**，早期方案仅作为设计演进记录保留。

---

## 一、当前实装方案

### 1.1 电源树

```text
XT60（主）/ 咪头（备）
        │
        ▼
  5 A 一次性保险丝
        │
        ▼
   LM2596S（DCDC，可调，2 A 级）
        │
        ├──────────────► 动力轨：TB6612 的 VM、IP65 舵机
        │
        └──────────────► 5 V 中间轨
                              │
                              ▼
                        ME6211（LDO）────────► 3.3 V 逻辑轨
                                                STM32 / ESP-01S / JY901S / OLED / CH340
```

### 1.2 器件分工与理由

| 轨道 | 器件 | 类型 | 输出 | 供给对象 | 选型理由 |
| --- | --- | --- | --- | --- | --- |
| 动力轨 | **LM2596S** | DCDC（开关式） | 可调，2 A 级 | TB6612 VM、舵机 | 效率高、可调、成熟量产件；带电机这类非线性负载发热远小于线性方案 |
| 3.3 V 逻辑轨 | **ME6211** | LDO（线性） | 3.3 V | MCU、ESP-01S、JY901S、OLED、CH340 逻辑 | 压差小、静态电流低、**无开关噪声**；JY901S 对纹波敏感，LDO 更稳 |

**为什么分两轨而不是一轨到底**：LDO 干净但效率低，适合 mA 级、怕纹波的逻辑器件；DCDC 有开关纹波但效率高，适合 A 级、不在乎纹波的动力器件。若用 DCDC 直供 3.3 V，电机的开关噪声会耦合进 IMU 供电，姿态数据将出现难以定位的跳变。

**为什么先降到 5 V 再降 3.3 V（两级降压）**：其一，舵机与 CH340 需要 5 V；其二，两级降压使每一级的压差都更小，发热更可控，比从电池一次跳到 3.3 V 更稳。

### 1.3 输入接口与保护

| 项 | 设计 | 说明 |
| --- | --- | --- |
| 主电源接口 | **XT60** | 接触电阻低、极性防呆、可反复插拔；航模电池标准接口 |
| 备用输入 | **咪头接口** | 与 XT60 双适配；台架调试可接实验室稳压电源，不必拆电池 |
| 过流保护 | **5 A 一次性保险丝** | 峰值按 2 A 级设计，留约 2.5 倍余量容纳堵转启动冲击 |

> ⚠️ 保险丝**只保护短路与严重过流，不保护接反**。电池正负极接反会直接击穿稳压模块与全部模组。上电前必须用万用表确认 XT60 极性。
>
> ⚠️ 保险丝熔断为**不可逆**，装机前建议备件若干。

### 1.4 未引入的器件

设计文档曾列出下列器件，**均未进入当前实装版本**，在此说明以免复刻者困惑：

| 器件 | 早期设想用途 | 现状 |
| --- | --- | --- |
| PCA9685 | 多路舵机 PWM 扩展 | **未采用**，舵机由 STM32 TIM3 直驱（PA6） |
| XL6019 / XL4016E1 | 升压至 12 V 供尾鳍电机 | **未采用**，当前动力轨由 LM2596S 直接提供 |
| AMS1117-3.3 | 5 V → 3.3 V 降压 | **已被 ME6211 替代**（压差更小、静态电流更低、成本更低） |
| MS5837 水深传感器 | 深度闭环 | **未实装**，属第二阶段增强项 |
| MAX485 / MAX3485 | 有线差分控制链路 | **未采用**，控制链路走 Wi-Fi TCP |
| WS2812 LED | 状态灯带 | **未采用**，状态指示用 PC13 单灯 |

---

## 二、早期阶段 B 方案（历史记录）

> 以下为 `仿生鱼项目 – 硬件电压汇总与电源方案设计.docx` v1.3（2026-06-22）的内容摘要，属**阶段 B 规划**，与当前 v1.0.0 实装方案不一致，仅作设计演进留档。

### 2.1 供电电压清单

| 元件 | 所需电压 | 电流需求 | 备注 |
| --- | --- | --- | --- |
| STM32F103 核心板 | 3.3 V | < 200 mA | 核心板一般无 LDO，不可直连 5 V |
| ESP32-S3 开发板 | 5 V（USB）或 3.3 V（Vin） | ~500 mA | 供电取决于具体型号 |
| PCA9685 VCC（逻辑） | 3.3 V 或 5 V | < 10 mA | 不可与 V+ 混用 |
| PCA9685 V+（舵机） | 6 V | 总和可达 10 A | 独立大电流轨；平均电流约为峰值 30%~50% |
| DS3218 防水舵机 | 6 V | 堵转 2.5 A/个 | 背鳍、腹鳍共 3 个 |
| 小舵机（20/25 kg） | 6~7.4 V（典型 6 V） | 堵转 ~2 A | 不可直连 2S 满电 8.4 V |
| 尾鳍电机 | 12 V | 堵转 ~1.5 A | 由 L9110S 驱动 |
| JY61P IMU | 3.3 V 或 5 V | < 25 mA | 串口通信 |
| MS5837 水深传感器 | 3.3 V | < 1 mA | I²C |
| OLED（0.96 寸） | 3.3 V | < 20 mA | I²C |
| CH341N | 5 V | < 20 mA | USB 转串口 |

### 2.2 早期电源树（阶段 B）

```text
2S 锂电池 7.4V（XT60 + 5A 保险丝）
   │
   ├── 大电流 DCDC（XL4016E1 或 MP1584 并联）7.4V→6V，输出 ≥6A ──► PCA9685 V+（所有舵机）
   ├── LM2596 7.4V→5V，输出 2A ──► ESP32-S3 / WS2812 / 5V 总线
   │                                   └── AMS1117-3.3 5V→3.3V ──► STM32 / JY61P / MS5837 / PCA9685 VCC / OLED / MAX485
   └── XL6019 7.4V→12V，输出 ≥2A ──► 尾鳍电机 12V
```

### 2.3 电压清单中已纠正的错误

早期物料清单存在若干电压标注错误，记录于此以免复现：

| 物料 | 清单标注 | 实际额定 | 后果 |
| --- | --- | --- | --- |
| DS3218 防水舵机 | 12 V ❌ | **4.8~6.8 V（典型 6 V）** | 接 12 V 会立即烧毁 |
| 汉普斯 17HS4401S-FS | 12 V ✅ | 12 V | 正确；该电机为已作废的步进方案电机 |
| Hkwuxian 20/25 kg 小舵机 | 未标 | **6~7.4 V** | 不可直连 2S 满电 8.4 V |
| MAX485 模块 | 未明确 | 3.3 V 或 5 V 版本 | 需确认版本，5 V 版须加电平转换 |
| OLED（0.96 寸） | 未提及 | 3.3 V（典型） | 少数模块支持 5 V，建议归 3.3 V 轨 |

---

## 三、通用原则

1. **峰值而非平均值选型**：舵机与电机的堵转电流为峰值，实际运行平均约为峰值 30%~50%，但器件与走线必须按**峰值**选择。
2. **逻辑地与功率地必须共地**，且回流路径要足够宽，否则大电流会在细走线上产生压降，表现为逻辑器件随机复位。
3. **功率电源不得由 MCU GPIO 提供**，必须经驱动级（TB6612）或独立轨道。
4. **每一级降压都应留压差余量**：LDO 尤其如此，ME6211 在输入低于约 3.5 V 时即跌出稳压区。

---

_整理日期：2026-09-24 ｜ 实装方案以 v1.0.0 为准_

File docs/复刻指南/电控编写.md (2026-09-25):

# ③ 电控编写

**目标**：能构建固件、看懂代码结构、按自己的需求改参数或扩展功能。

**完成标志**：能独立完成「改一个参数 → 构建 → 烧录 → 用串口验证」的完整循环。

---

## 一、构建环境

### 1.1 固定依赖

| 组件 | 版本 |
| --- | --- |
| STM32CubeF1 | **v1.8.6**（与 `bionic_fish.ioc` 一致），commit `42472d60…` |
| Arm GNU Toolchain | **13.3.Rel1**，目标 `arm-none-eabi` |
| CMake | 3.31.8（工程最低 3.20） |
| Ninja | 1.12.1 |
| Python | 3.9+（仅构建包装脚本需要） |
| 主机测试编译器 | GCC / Clang（**必须与 Arm 工具链分开**） |

> ⚠️ **版本不能随意替换。** CMake 会拒绝非 v1.8.6 的 CubeF1 `package.xml`。下载地址与校验值固定在 `dependencies.lock.json`。

### 1.2 首次构建（Windows）

在 `STM32控制工程` 目录：

```powershell
python scripts/build.py firmware --bootstrap
python scripts/build.py host --bootstrap --host-cc C:/path/to/native-gcc.exe
```

- `--bootstrap` 会自动下载校验后的工具与固定版本 CubeF1，默认缓存到 `%LOCALAPPDATA%/bionic-fish-build`；**第二次不需要再加这个参数**。
- 所有 PATH 设置**只传给本次子进程**，不修改你的全局环境，也不自动烧录。

> ⚠️ **宿主测试不要指定 `arm-none-eabi-gcc`** —— 它生成不了能在电脑上跑的程序。若本机 `gcc` 已配好，`--host-cc` 可省略。

### 1.3 Linux / macOS

```sh
python3 scripts/build.py firmware --bootstrap --toolchain-bin /opt/arm-gnu-toolchain/bin
python3 scripts/build.py host --host-cc /usr/bin/gcc
```

或不用 Python，直接走 CMake：

```sh
cmake -S . -B build-firmware -G Ninja \
  -DCMAKE_TOOLCHAIN_FILE=cmake/arm-none-eabi-gcc.cmake \
  -DARM_TOOLCHAIN_BIN=/path/to/arm/bin \
  -DSTM32CUBE_F1_PATH=/path/to/STM32Cube_FW_F1_V1.8.6 \
  -DBIONIC_FISH_BUILD_FIRMWARE=ON -DBIONIC_FISH_BUILD_HOST_TESTS=OFF \
  -DCMAKE_BUILD_TYPE=MinSizeRel -DBIONIC_FISH_WERROR=ON
cmake --build build-firmware --parallel
```

> 📌 换编译器或生成器时**必须换新的 `--build-dir`**，不要复用另一工具链的 CMake 缓存。

### 1.4 产物

输出在 `build-firmware/`：`bionic_fish.elf`、`bionic_fish.bin`、`bionic_fish.map`，另生成 `build-info.json`（记录编译器、CubeF1、源提交、是否有未提交修改、产物 SHA-256）。

**参考基线**：BIN 约 **34,272 字节**，Flash 占用 **52.29%**、RAM **79.92%**。

> ⚠️ **RAM 已用近 80%，加功能前先算内存账。** 链接脚本限定 64 KiB Flash / 20 KiB SRAM，预留 0x200 堆与 0x800 栈，超区会直接链接失败。

---

## 二、代码结构

固件约 **6,000 行 C**，严格分层。`main.c` 只做初始化与主循环调度，业务逻辑不堆在入口文件。

```text
STM32控制工程/
├── Core/          CubeMX 生成层（时钟、GPIO、TIM、USART）
├── app/           应用层
│   ├── app.c          主循环调度、命令分发、超时检查
│   └── app_config.h   ★ 全部可调参数的唯一入口
├── bsp/           板级支持层
│   ├── bsp_board.c    板级初始化、紧急 coast
│   ├── bsp_time.c     32 位微秒时基（TIM4 扩展）
│   ├── bsp_uart.c     环形缓冲收发、错误回调
│   └── esp_link.c     ★ ESP-01S AT 状态机
├── protocol/      协议层
│   ├── ascii_protocol.c  V1 ASCII 组帧/解析/校验
│   ├── http_ui.c         内嵌网页控制页
│   └── ring_buffer.c     无锁环形缓冲
├── cmake/         工具链与链接脚本
├── scripts/       构建、烧录、串口工具
└── tests/         主机回归测试
```

> 📌 完整的控制层（`motor_control.c` / `servo_control.c`）、驱动层（`soft_i2c.c` / `ssd1306.c` / `jy61p.c`）、界面层（`oled_ui.c`）分文件同属上述体系，职责边界按目录划分。

### 2.1 五条设计原则（改代码时请遵守）

**① 中断只做搬运，主循环做决策**
UART 中断仅把字节写入固定大小环形缓冲，完整帧解析在主循环完成。中断里不做阻塞业务，也不直接驱动执行器。

**② 固定内存，无动态分配**
所有缓冲、字段表、状态槽均为固定大小数组，业务代码**不使用 `malloc`**。这保证 RAM 占用可预测，也避免长期运行的碎片化风险。

**③ 配置集中于单一入口**
所有可调参数集中在 `app_config.h`，并配编译期静态校验。定时器折算、占空比边界、舵机行程一致性全部在**构建期**拦截。

**④ 用编译期门禁防止回归**
曾因缓冲不匹配导致「网页静默发不出去」：响应缓冲 4096 字节，传输缓冲只有 3584，**超长一个字节都发不出去，而串口上 `error=OK`，整个失败过程完全静默**。

修复后加了门禁：

```c
/* esp_link.c —— 今后只要有人再让传输缓冲小于响应缓冲，构建直接失败 */
static char kHttpRawMustFitResponse[
    (HTTP_RAW_BYTES >= HTTP_RESPONSE_BYTES) ? 1 : -1];
```

**⑤ 执行器动作原子化**
任何解析、语义或序号失败，都**不能造成部分电机或舵机动作**。协议栈在校验全部通过前不触碰执行器。

---

## 三、配置方法

### 3.1 改参数

**所有可调项都在 `app/Inc/app_config.h`**，不要在业务代码里写魔数。

| 想改什么 | 配置项 | 当前值 |
| --- | --- | --- |
| 满速挡占空比 | `CFG_MOTOR_FULL_DUTY_PERCENT` | `95U`（**不要改成 100**） |
| 低速挡占空比 | `CFG_MOTOR_LOW_DUTY_PERCENT` | `60U` |
| 单独禁用 M1 | `CFG_MOTOR_A_ENABLED` | `1U` |
| 单独禁用 M2 | `CFG_MOTOR_B_ENABLED` | `1U` |
| 失联超时 | `CFG_LINK_TIMEOUT_MS` | `1000UL` |
| 状态帧周期 | `CFG_STATUS_PERIOD_MS` | `200UL` |
| 舵机安全行程 | `CFG_SERVO_SAFE_MIN/MAX_DEG` | `-15` / `15` |
| 失联是否回中 | `CFG_SERVO_CENTER_ON_LINK_TIMEOUT` | `1U` |
| Wi-Fi 模式 | `CFG_ESP_WIFI_MODE` | `2U`（**必须是 2**） |
| AP 名称/密码 | `CFG_ESP_AP_SSID/PASSWORD` | `BionicFish-AP` / `12345678` |
| 端口 | `CFG_ESP_TCP_PORT` | `9000U` |
| 调试按键 | `CFG_DEBUG_BUTTONS_ENABLED` | `1U`（**下水前必须改 0**） |
| 两挡 PWM 定时器 | `CFG_MOTOR_TIM_PRESCALER/PERIOD` | `7199U` / `19999U`（→ 2 s 周期） |

### 3.2 两处「改了就坏」的配置

**① `CFG_MOTOR_FULL_DUTY_PERCENT` 不要改成 100。**

100% 会让 `CCR = ARR + 1`，PWM 恒高、**永不产生下降沿**，TB6612 自举电容无法刷新，结果就是「有电压却带不动负载」。**95% 是功能必需，不是保守取值。**

**② `CFG_ESP_WIFI_MODE` 不要改成 3。**

双模会导致网页完全打不开（原因见 [通信调试.md](通信调试.md)）。要启用 3，**必须同时实现 `AT+CWJAP` 下发**。

### 3.3 下水的强制动作

```c
#define CFG_DEBUG_BUTTONS_ENABLED   0U   /* 1U → 0U */
```

> 🔴 **这一项是安全项，不是功能项。** 调试按键功能有意放开了「无链路即无运动」的看门狗保证 —— K1 启动的转动在**完全没有上位机时会一直持续**。

---

## 四、验证方法

### 4.1 三层验证

```text
① 主机回归测试   → 逻辑对不对（在 PC 上跑，秒级）
② Arm 交叉构建   → 能不能编进芯片（编译期门禁在这一层拦截）
③ 目标板实测     → 实物行为对不对（唯一能证明硬件的）
```

**前两层通过不代表第三层通过。** 顺序执行，不要跳。

### 4.2 主机测试

```sh
python scripts/build.py host --host-cc /usr/bin/gcc
```

基线：**16/16 通过**（含编译期门禁）。

> 📌 Release / MinSizeRel 构建**也保留断言**，不要为了性能关掉。

### 4.3 目标板验收

见 [验收检查清单.md](../../仿生鱼完整项目交付包_v1/仿生鱼完整项目交付包/STM32控制工程/验收检查清单.md)。核心判据：

- 两路电机可同时下达方向（`move=` 与 `m2=`），互不覆盖；
- STOP / 失联 / UART 丢失使**两路同时 coast**；
- 舵机 ±15° 限幅，±16° 返回 `E_RANGE`；
- 网页左键确实左转、右键确实右转（方向不双重取反）。

---

## 五、扩展实践

### 5.1 扩展一：把唧筒限位开关接进固件

**当前状态**：机械件的限位开关**已设计但未接线**，活塞行程保护需自行补充。这是最值得做的第一个扩展。

思路：

1. 选两个空闲 GPIO 作限位输入（配置为输入 + 内部上拉，低有效）。
2. 在 `app_config.h` 增加限位引脚与消抖时间配置。
3. 在主循环中轮询限位状态；**触发时立即令 M2 coast**，并置一个故障位。
4. 在 `m2` 命令的下发路径上加前置判断：若已触发同向限位，直接拒绝并回 `ERR`。

> ⚠️ 注意原则 ⑤：限位触发必须**只停 M2，不影响 M1 与舵机**。不要写成全局急停。

### 5.2 扩展二：修复 App 连上就断

**当前状态**：`AT+CIPSTO=3` 使 ESP 3 秒空闲即断开，而 App 在无命令时只 delay、不发帧，导致反复重建连接。**已知未修复。**

两个方向，任选其一：

| 方向 | 做法 | 取舍 |
| --- | --- | --- |
| 放宽 `CIPSTO` | 改为 30 s | 改动最小，但断链检测变慢 |
| App 发心跳 | 加一个低频 keepalive 命令 | 更健壮，但需同时改协议与 App |

> 📌 若选心跳方案，建议新增独立的帧类型（如 `KEEP`）而非复用 `CMD`，避免污染控制语义与序号窗口。

### 5.3 扩展三：支持多控制客户端

**当前状态**：固件只接受**单个**控制客户端，安卓与网页无法同时连接。

`CFG_ESP_MAX_CLIENTS` 当前为 `4`，但**协议层只维护一个会话槽位**。要真正支持多客户端，需要在会话层维护多组「序号窗口 + 保活计时」，并决定：

- 多客户端命令冲突时谁优先？（建议后到者覆盖，或直接拒绝）
- 断线时是否只清对应那个会话的窗口？

> ⚠️ 这是**结构性改动**，不是改个宏的事。改之前先把序号窗口与会话生命周期的关系想清楚。

### 5.4 扩展四：加一个传感器（以 MS5837 水深为例）

1. **接总线**：两条软件 I²C 已各自占用，建议复用 IMU 那条（`PB6/PB7`，注意地址不冲突）。
2. **加驱动**：仿照 `jy61p.c` 写一个固定内存、带失败计数的读函数。
3. **加状态字段**：在 `STA` 中新增字段。**新增字段是向后兼容的**（未知字段会被忽略），但请确认 App 侧不会因此解析失败。
4. **加故障位**：在 `faults.h` 中占用 bit 6（当前预留）—— ⚠️ **bit 7/8 的位置不得前移**，否则会破坏既有位图语义。

### 5.5 扩展的通用检查清单

- [ ] 新参数是否加进了 `app_config.h` 并配了编译期校验？
- [ ] 是否引入了动态分配？（不允许）
- [ ] 中断里是否做了决策？（不允许）
- [ ] 失败路径是否可能造成**部分执行器动作**？（不允许）
- [ ] RAM 增量是否算过？（余量只剩约 20%）
- [ ] 是否跑了主机回归测试？
- [ ] 是否在实板上验证过？

---

## 六、CubeMX 再生成政策（重要）

> 🔴 **禁止在交付源码目录直接点 Generate Code，并把结果当作可烧录版本。**

CubeMX 的 `KeepUserCode` **只保护 USER CODE 区**，无法保留自定义的完整时钟映射、MSP、安全 GPIO 初始化、HAL 配置和构建源列表。

正确流程：

1. 把 `bionic_fish.ioc` 复制到**仓库之外的临时目录**，用 CubeF1 **v1.8.6** 生成。
2. 对比生成文件与受维护 `Core/` 的差异，**只合并本次需要的引脚/外设变更**；同步更新 `.ioc` 与 `app_config.h`。
3. 保留 `main.c` 中已标记的 Includes、PD、2、3、4 与 `Error_Handler_Debug` 区域。**必须存在** `BSP_Time_Init`、`App_Init`、循环中的 `App_Process`，以及 TIM4、UART RX/TX/Error 回调向 BSP 的转发。
4. 特别复查：**两桥启动 coast**、舵机初始脉宽、TIM4 更新中断、USART2/3、SWD、两条软件 I²C 的开漏配置。保留标准 `assert_param` 定义与 `Core/Src/assert.c`。
5. 完整执行主机测试 + 固件交叉构建，再上板空载验收。

---

## 七、调试技巧

### 7.1 利用双通道

```text
改代码 ──► SWD 烧录 ──► 串口读 STA/诊断 ──► 定位 ──► 再改
```

**串口是主要的信息来源。** 全链路诊断都通过 USART3 以纯文本输出，包括：

- `ESP server=… tcp=… reset=… error=…` —— 链路状态
- `IMU scl= sda= st= probe=` —— IMU 三段诊断
- `STA` 状态帧 —— 完整运行状态与故障位图

### 7.2 已知的烧录坑

烧录报 `failed to erase memory` / `failed to download Sector[0]` 时：

**先用「写 RAM `0x20000000`」做对照实验** —— RAM 成功而 flash 失败，即可判定为 **MCU 内部 flash 故障**，与代码无关，需换芯片。

> ⚠️ `-e all` 报「Mass erase successfully achieved」**不表示擦除真的生效**。

### 7.3 构建诊断的正常现象

Arm GNU 13.3.Rel1 的 `newlib-nano/nosys` 在库解析阶段会报 `_close`、`_lseek`、`_read`、`_write` 未实现。**这是正常的** —— 这些符号随后被链接垃圾回收，不保留在最终 ELF 中。串口收发由 BSP 实现。

---

## 参考

| 内容 | 位置 |
| --- | --- |
| 完整构建说明 | [`scripts/BUILDING.md`](../../仿生鱼完整项目交付包_v1/仿生鱼完整项目交付包/STM32控制工程/scripts/BUILDING.md) |
| 协议字段与错误码 | [`通信协议.md`](../../仿生鱼完整项目交付包_v1/仿生鱼完整项目交付包/STM32控制工程/通信协议.md) |
| 引脚与驱动细节 | [`硬件引脚与驱动说明.md`](../../仿生鱼完整项目交付包_v1/仿生鱼完整项目交付包/STM32控制工程/硬件引脚与驱动说明.md) |
| 验收判据 | [`验收检查清单.md`](../../仿生鱼完整项目交付包_v1/仿生鱼完整项目交付包/STM32控制工程/验收检查清单.md) |
| 开发过程与踩坑 | [`开发日志与修改清单.md`](../../仿生鱼完整项目交付包_v1/仿生鱼完整项目交付包/STM32控制工程/开发日志与修改清单.md) |

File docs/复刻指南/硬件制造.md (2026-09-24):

# ① 硬件制造

**目标**：得到一台能安全通电、能被电脑识别、各模块可独立替换的裸机。

**完成标志**：上电后 PC13 指示灯每 500 ms 翻转；Type-C 接电脑能在串口助手里看到输出；XT60 供电正常、两轨电压分别正确。

---

## 一、采购清单

按功能分组。**建议每类多买一件备件** —— 本项目的设计取向就是「用换件定位故障」，有备件能让调试快很多。

### 1.1 主控与通信

| 器件 | 关键规格 | 备注 |
| --- | --- | --- |
| STM32F103C8T6 最小系统板 | LQFP48，64 KiB Flash / 20 KiB RAM | 需 **32 针**排针引出，配合母座插接 |
| ESP-01S 模组 | ESP8266，**必须带 AT 固件** | AT 1.7.4.0 / SDK 3.0.5-dev 已在实物验证；见 [通信调试.md](通信调试.md) |
| CH340 芯片（板载） | USB 转串口 | 引 Type-C 母座；与 SWD 构成双通道调试 |
| ST-Link V2 | SWD 烧录器 | 用于烧录与断点 |

> ⚠️ ESP-01S 请**确认是 AT 固件版本**，不是需要自己刷 SDK 的裸模组。市面上有大量 ESP-01S 出厂无固件或固件版本不符。

### 1.2 驱动与执行

| 器件 | 关键规格 | 备注 |
| --- | --- | --- |
| TB6612FNG 模块 | 双 H 桥 | 单芯片同时驱动 M1 与 M2，是本方案的核心 |
| 370 直流减速电机 | 12 V | **M1**，尾段主推进 |
| N20 直流减速电机 | **12 V 版** | **M2**，驱动唧筒活塞 |
| IP65 防水舵机 | 6 V 级 | 转向；安全行程 ±15° |
| 100 ml 注射器 | 医用规格 | 唧筒筒体（沉浮机构） |
| 微动开关 ×2 | 常开 | 唧筒行程两端限位 |

> ⚠️ **N20 务必买 12 V 版**。若用 6 V 版，满压运行会超压，必须先降占空比（约 50%）或改供电。

### 1.3 传感与显示

| 器件 | 关键规格 | 备注 |
| --- | --- | --- |
| JY901S 姿态模块 | 兼容 JY61P | 内部完成姿态解算，直接读角度 |
| SSD1306 OLED | 128×64，I²C | 单页状态屏 |
| 4.7 kΩ 电阻 ×2 | 1/4 W | **JY901S 软件 I²C 必需的外部上拉** |

> 📌 实物为 **JY901S**（非原理图标注的 JY61P），对本工程协议无影响，寄存器映射需按实际模块核对。

### 1.4 电源与保护

| 器件 | 关键规格 | 备注 |
| --- | --- | --- |
| ME6211 | 3.3 V LDO | 逻辑轨；压差小、无开关噪声 |
| LM2596S 模块 | DCDC 可调，2 A 级 | 动力轨 |
| XT60 公母头 | — | 主电源接口 |
| 咪头接口 | — | 备用输入，台架接稳压源用 |
| **5 A 一次性保险丝** + 座 | — | 短路保护；建议备 3~5 只 |
| 3S 航模锂电 | 45C | 约 12 V；需另配平衡充 |

> ⚠️ **一次性保险丝熔断后不可恢复**，必须更换。请务必准备备件。

### 1.5 结构、接口与耗材

| 器件 | 关键规格 | 备注 |
| --- | --- | --- |
| 拓展板 PCB | 自研，单次打样 | 只做引脚扇出与电源分配，不做信号处理 |
| 32 针母座 | 2.54 mm | 固定 STM32 核心板，支持拔换 |
| 排针 / 排母 | 2.54 mm，若干 | UART、电机、舵机接口全部扇出 |
| Type-C 母座 | — | 接板载 CH340 |
| PETG 耗材 | 1.75 mm | 结构件打印；**不用 PLA** |
| 紧固件、密封件 | M3 等 | 装配 |

---

## 二、电路与接线

### 2.1 电源链路

```text
XT60（主）/ 咪头（备）
        │
        ▼
  5 A 一次性保险丝
        │
        ▼
   LM2596S（DCDC 可调）
        │
        ├──────────────► 动力轨：TB6612 的 VM、舵机
        │
        └──────────────► 5 V 中间轨
                              │
                              ▼
                        ME6211（LDO）────────► 3.3 V 逻辑轨
                                                STM32 / ESP-01S / JY901S / OLED / CH340
```

**为什么分两轨**：LDO 干净但效率低，给 mA 级、怕纹波的逻辑器件；DCDC 有开关纹波但效率高，给 A 级、不在乎纹波的动力器件。**JY901S 对电源纹波敏感**，若用 DCDC 直供 3.3 V，电机启停会让姿态数据出现难以定位的跳变。

详见 [电源方案与电压汇总.md](../../电气设计说明/电源方案与电压汇总.md)。

### 2.2 引脚接线

| 功能 | STM32 引脚 | 接到 |
| --- | --- | --- |
| M1 PWM | `PA0` | TB6612 `PWMA` |
| M2 PWM | `PA1` | TB6612 `PWMB` |
| M1 方向 | `PB12` / `PB13` | TB6612 `AIN1` / `AIN2` |
| M2 方向 | `PB14` / `PB15` | TB6612 `BIN1` / `BIN2` |
| 舵机 | `PA6` | 舵机信号线 |
| ESP 通信 | `PA2` / `PA3` | ESP-01S `RXD` / `TXD`（**交叉**） |
| CH340 调试 | `PB10` / `PB11` | CH340 `RX` / `TX`（**交叉**） |
| JY901S I²C | `PB6` / `PB7` | 模块 `SCL` / `SDA`（**需 4.7 kΩ 上拉到 3.3 V**） |
| OLED I²C | `PB8` / `PB9` | 模块 `SCL` / `SDA` |
| 调试按键 | `PB0` / `PB1` / `PA8` | K1 / K2 / K3 |
| 运行指示 | `PC13` | 板载 LED |
| SWD | `PA13` / `PA14` | SWDIO / SWCLK |

**接线要点**：

- **TB6612 的逻辑电源接 3.3 V**，电机功率电源接动力轨（约 12 V）；逻辑地与功率地**必须共地**。
- **两条软件 I²C 互相独立**：`PB6/PB7` 是 IMU 总线，`PB8/PB9` 是 OLED 总线，排查时不要互相推断。
- **一路 I²C 一路诊断**：`I2CSCAN` 报 OLED 总线、`IMUSCAN` 报 IMU 总线。
- ESP-01S 的 `RST` / `EN` / `IO0` / `IO2` **悬空即可**，不要误接到 STM32。
- **电机端绝不能直接接 STM32 GPIO。**

### 2.3 三条接线纪律

1. **上电前用万用表确认 XT60 极性。** 保险丝不防接反，接反会击穿所有模组。
2. **两轨不得共用细走线或窄地回流路径。** 若出现「电机一动、IMU / OLED 就异常复位」，首要怀疑逻辑轨被动力轨污染。
3. **先调好 LM2596S 输出再接负载。** 直接用电池接电机，若 DCDC 输出未调对会超压。

---

## 三、结构件制造

### 3.1 尾段零件（已开源）

可发布的尾段零件在仓库根目录 [`鱼尾装配/`](../../鱼尾装配/README.md)，含 SolidWorks 原生件与 STEP 交换格式。

| 类别 | 文件 | 状态 |
| --- | --- | --- |
| 承载支撑 | `尾部左支撑V6F.step`、`右支撑V4F.step` | **当前版本** |
| 传动 | `套筒.SLDPRT`、`摇杆.SLDPRT`、`moto shef.SLDPRT`（电机座） | **当前版本** |
| 连接 | `U型件.SLDPRT`、`鱼体第二关节.step.SLDPRT` | **当前版本** |
| 快拆 | `快拆架.SLDPRT`、`防水盒快拆.SLDPRT` | **当前版本** |
| 装配参考 | `尾部装配2.SLDASM` | 参考装配 |

> ⚠️ `右支撑V2.SLDPRT` 与 `测试装配.SLDASM` 是**历史版本**，仅作对比，**不要用于打印**。

**打印参数建议**：

- 支撑件是主要承力件，材料用 **PETG**，**壁厚不低于 3.2 mm，填充率 40% 以上**。
- 关节与快拆件**先试打印单件**确认配合间隙，再批量打印。
- 部分零件的装配间隙与止口需根据实际打印精度微调。

### 3.2 外壳

外壳为**参数化建模**产物（Python 型线表驱动），整机全长 700 mm，分头 / 体 / 尾三段，壁厚 3.2 mm。

> ⚠️ **脚本产出的网格不是单一水密实体**，是多部件叠加。直接 3D 打印前需先在 CAD / 切片软件中做**布尔合并**，否则切片会异常。

**制造级工作必须在 CAD 中完成**：止口、密封槽、螺钉孔、装配间隙。脚本产物的定位是**外观与装配参考**，不作为最终加工依据。内部电气（电池盒、控制器）未建模，无需照搬。

### 3.3 唧筒（沉浮机构）

```text
N20 直流减速电机
    │
    └─► 马达齿轮 ──► 大齿轮（减速）──► 螺杆 ──► 活塞
                                          │
                            100 ml 注射器筒体 ──► 排水体积变化
                                          │
                          微动开关 ×2 ◄────┴──── 行程两端限位
```

装配要点：

- **螺杆自锁**是断电保位的关键，装配后手动推拉活塞应感到明显阻力、松手不回退。
- **两个微动开关**装在行程两端，防止螺杆顶死导致电机堵转。
- ⚠️ **限位开关接线尚未纳入当前固件**，需在整机联调时补充（见 [电控编写.md](电控编写.md) 扩展章节）。
- ⚠️ 活塞在筒体内的**动密封是全机防水的关键风险点**，必须实测确认。

---

## 四、上电前检查清单

**逐项打勾，不要跳。**

- [ ] 用万用表确认 XT60 极性正确（**保险丝不防反接**）
- [ ] 5 A 保险丝已装好，**未被导线短接**
- [ ] 断开负载，单独测 LM2596S 输出，调到电机/舵机额定电压
- [ ] 测 ME6211 输出为 **3.3 V**（输入低于约 3.5 V 会跌出稳压区）
- [ ] 两轨地线共地，且地回流路径足够宽
- [ ] JY901S 的 `PB6/PB7` **已焊 4.7 kΩ 上拉**
- [ ] ESP-01S `PA2/PA3` 交叉收发正确
- [ ] TB6612 `STBY` 已接 3.3 V 高电平（低电平会让两桥输出高阻）
- [ ] 电机端未直接接 GPIO
- [ ] `CFG_DEBUG_BUTTONS_ENABLED` 确认为 **0**（见下方警告）

---

## 五、首次上电

### 5.1 上电顺序

1. **先不接电机与舵机**，只上逻辑部分，确认 3.3 V 轨正常、PC13 指示灯按 500 ms 翻转。
2. **接 Type-C 到电脑**，在串口助手中应能看到周期性输出。看不到就停下排查，不要继续。
3. **再接 SWD**，确认 ST-Link 能识别芯片。此时双通道应可同时工作。
4. **最后接动力轨负载**（TB6612 VM、舵机），逐路确认。

### 5.2 判断「MCU 是否在跑」

最快的方法：**看串口有没有输出**。有输出说明固件在运行、时钟配置正确；无输出则优先怀疑供电、时钟或烧录未成功。

---

## 六、常见问题

| 现象 | 排查方向 |
| --- | --- |
| 全板无电、串口无输出 | **先查保险丝是否熔断**（不可逆，需更换）；再查 XT60 是否插到位 |
| 上电即烧毁模组 | **极大概率是 XT60 极性接反**，用万用表确认 |
| 逻辑轨不是 3.3 V | 查 ME6211 输入是否正常、输出电容是否虚焊 |
| 动力轨电压不对 / 电机无力 | 调 LM2596S 电位器；确认未低于最小工作压差、未触发限流 |
| 电机一转 IMU/OLED 就复位 | **两轨未隔离干净**，检查共用细走线或地回流路径过窄 |
| 电机不转但接线无异常 | **优先查 TB6612 的 STBY**，低电平会让两桥输出全部高阻 |
| 有 12 V、STBY 已拉高却带不动 | **占空比是否为 100%？** 见本文开头「三个坑」第 1 条 |
| 屏能显示但 IMU 读不到 | **`PB6/PB7` 缺 4.7 kΩ 外部上拉**（`IMU … pu=11` 即为该判据） |
| 烧录报 `failed to erase memory` | 先用「写 RAM」做对照实验排除 MCU 内部 flash 故障 |

---

## 七、安全须知

> 🔴 **下水前必须确认**：
>
> 1. **`CFG_DEBUG_BUTTONS_ENABLED` 已设回 `0`。** 该调试功能有意放开了「无链路即无运动」的看门狗保证 —— K1 启动的转动在**完全没有上位机时会一直持续**。
> 2. 两路电机与舵机已装好机械保护，可立即断电。
> 3. 已完成台架启停、失联、ESP 复位与供电恢复测试。
> 4. 95% / 60% 均为**开环电压设定，不是限流或过流保护**。TB6612 **无过流/短路保护规格**，堵转电流必须实测。
> 5. 唧筒活塞的动密封已实测确认。

---

## 下一步

硬件能通电、串口有输出后，进入 [② 通信调试](通信调试.md)。

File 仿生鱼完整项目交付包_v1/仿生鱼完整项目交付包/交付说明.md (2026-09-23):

# 仿生鱼当前交付说明

2026-09-09 工作区修订：最终系统为 STM32F103C8T6 + ESP-01S AT/TCP + Android；HarmonyOS 暂停。本轮没有发布新 GitHub Release。目录中的 v0.3.1/v0.3.0 名称为既有归档名称，组件可以独立版本化。

## 有效入口

- `STM32控制工程/`：固件源码、固定依赖构建脚本、主机回归测试和当前硬件/协议说明。按该目录 README 构建后使用 `build-firmware/` 的产物及哈希记录。
- `仿生鱼安卓AP直连_v0.3.0_2026-09-06/Android工程/`：Android 源码，当前版本 0.3.2（versionCode 5）。设备页 AP 直连使用 Wi-Fi 专用 TCP Socket。
- 同级 `仿生鱼控制器_v0.3.0_AP直连.apk`：历史版本，不能当作本轮固定低速版本的产物。新 APK 以 Android `app/build/outputs/apk/debug/` 为准。
- `原始资料/`：板级输入资料，其中历史设想不覆盖当前代码和配置。

## 当前范围

两路直流减速电机（M1 = 370 主推进、M2 = N20 12V 版）分别使用 TB6612 的两个 H 桥，各自独立启停与换向；一路舵机（安全行程 ±20°），JY61P 姿态和 SSD1306 单页显示。按键暂不使用。HarmonyOS/ESP32 WebSocket 或自定义 ESP 透明桥不在本轮链路；旧透明桥保留在 STM32 legacy/，不参与当前构建/烧录。

## 验收状态

**host 侧 17/17 通过（10 个可执行 + 7 个编译期门禁）。**—**Arm 交叉构建尚未重做：下面这段 BIN 尺寸/哈希属于改动前的旧固件，双直流电机版本必须重新构建后以新产物为准。**（原文）固定低速版本通过17/17 CTest和Arm交叉构建，BIN24,604字节；Android0.3.2/code5通过56/56单元测试和23/23 MuMu设备测试，lint0错误，APK20,389,118字节。最终产物及哈希见STM32 build-firmware/build-info.json和Android验证记录。

默认推进为**满占空比（100%）**运行：M1、M2 各自独立方向，无换相节拍；STOP、失联、接收丢失或发送故障时两路同时 coast。100% 是开环满压设定，**不是限流或过流保护**（TB6612 无过流保护规格），必须实测电流与温升。安卓端需按交付方案升级后才能控制 M2。

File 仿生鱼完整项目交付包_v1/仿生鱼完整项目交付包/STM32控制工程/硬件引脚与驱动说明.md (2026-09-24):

# 硬件引脚与驱动说明

## 1. 当前接线结论

2026-09-23 更新：推进方案已由「42 两相双极步进 + 软件四拍换相」改为「**两路直流减速电机**」：**M1 = 370 直流减速电机**（带动鱼尾，接 TB6612 A 桥）、**M2 = N20 直流减速电机（12V 版本）**（驱动注射器式唧筒活塞，接 B 桥）。两路各自独立启停与换向，**不再有换相表、相序与线圈配对**。VM 仍为 12 V，TB6612 仍是双 H 桥：`PWMA/PWMB` 给占空比、`AIN/BIN` 给方向。V1.0.0 起 M2 唧筒链路已实装，可由协议 `m2=` 字段正确调用。

本轮针对「STBY 已接高、VM 为 12 V 却带不动负载」做了两处驱动侧改动：**TIM2 载波由 20 kHz 改为 2 s 慢周期**，**满速挡占空比由 100% 改为 95%**（原因见 §3.3）。用户已确认实物 STBY 恒接高电平、VM = 12 V。

本文件引脚表已与当前 `main.h`、GPIO 和定时器配置核对。旧 `CFG_STEPPER_STOP_ON_LINK_TIMEOUT` 开关已删除，当前失联始终停机。最新配置和实物确认记录维护在本文件。

两路电机各自只有两根线（正/负），接法错只会反转，不会像步进那样"抖动/堵转"。原先关于"必须确认四线双极、不得只用一个桥"的约束随步进方案一并作废。N20 为 **12 V 版本**（已实装验证），若日后换成 6V 版本，必须先降占空比（约 50%）或改供电，否则满压运行会超压。

### 1.1 板级背景：拓展板与电源架构

本工程运行在一块自研拓展板上，核心板以 **32 针母座**插接，UART 与电机、舵机接口**全部排针扇出**，全部功能模组分立可拔换。设计取向沿用 TI 杯电子设计竞赛的模组化范式：**任一模块异常应可拔换定位，而不是在板上飞线排查**。

**双通道调试（本工程的关键调试手段）**：

| 通道 | 接口 | 引脚 | 用途 |
| --- | --- | --- | --- |
| SWD | ST-Link | `PA13` / `PA14` | 烧录、断点、halt 查寄存器 |
| 串口 | 板载 CH340 + Type-C | `USART3`（`PB10` / `PB11`） | 运行期日志与状态帧 |

两者使用**独立的物理通道**，可同时接在同一台主机上，构成「**改代码 → 烧录 → 读日志 → 再改**」的可闭环调试环境，也是 AI Agent 联合调试能落地的前提。协议选用可打印 ASCII（见 `通信协议.md`）正是为了让串口侧输出可被工具直接解析。

**电源架构**：

```text
XT60 / 咪头 ──► 5 A 一次性保险丝 ──► LM2596S (DCDC, 可调)
                                        │
                              ┌─────────┴──────────┐
                              ▼                    ▼
                        动力轨：TB6612 VM、舵机   5 V 中间轨
                                                   │
                                                   ▼
                                        ME6211 (LDO) ─► 3.3 V 逻辑轨
                                        MCU / ESP / JY901S / OLED / CH340
```

| 轨道 | 器件 | 说明 |
| --- | --- | --- |
| 3.3 V 逻辑轨 | **ME6211**（LDO） | 低噪声，供给 MCU、ESP-01S、JY901S、OLED、CH340 逻辑；JY901S 对电源纹波敏感，故不用 DCDC 直供 |
| 动力轨 | **LM2596S**（DCDC） | 可调、2 A 级输出，供给 TB6612 的 VM 与舵机 |
| 输入保护 | **5 A 一次性保险丝** | 峰值按 2 A 级设计，留约 2.5 倍余量容忍堵转启动冲击；选一次性件以求短路时彻底切断 |

> ⚠️ 保险丝**只保护短路与严重过流，不保护接反**。上电前必须用万用表确认 XT60 极性。
>
> ⚠️ **两轨不得共用细走线或窄地回流路径**。若出现「电机一动、IMU 或 OLED 就异常复位」，首先怀疑逻辑轨被动力轨的电流冲击污染。

## 2. 引脚核对

| 功能 | 信号 | STM32F103C8T6 引脚 | 配置/边界 |
| --- | --- | --- | --- |
| M1 PWM（370） | `PWMA` | PA0 | TIM2_CH1 PWM，接 TB6612 A 桥；占空比随挡位取 `CFG_MOTOR_FULL_DUTY_PERCENT` / `CFG_MOTOR_LOW_DUTY_PERCENT`（当前 **95% / 60%**）。 |
| M2 PWM（N20 唧筒） | `PWMB` | PA1 | TIM2_CH2 PWM，接 TB6612 B 桥；同上，两路共用同一挡位（当前 **95% / 60%**）。 |
| M1 方向 | `AIN1` / `AIN2` | PB12 / PB13 | 推挽 GPIO，决定 A 桥电流方向/coast。 |
| M2 方向 | `BIN1` / `BIN2` | PB14 / PB15 | 推挽 GPIO，决定 B 桥电流方向/coast。 |
| M1 输出 | `M1+` / `M1-` | TB6612 A01/A02 | 接 370 直流减速电机的两根引线；接反只会反转。 |
| M2 输出 | `M2+` / `M2-` | TB6612 B01/B02 | 接 N20（12V 版）唧筒电机的两根引线；接反则活塞推拉方向互换。 |
| STBY（可选软件控制） | `STBY` | PB5（`CFG_MOTOR_STBY_PIN_ENABLED=1` 时启用） | **当前默认 0 = 不占用 PB5**，实物 STBY 恒接高电平；置 1 后固件在启动 PWM 前把 PB5 推挽输出拉高。 |
| IP65 舵机 | `SIG` | PA6 | TIM3_CH1，50 Hz 脉冲；实际脉宽和 3.3 V 兼容性待测。 |
| SSD1306 | `SCL` / `SDA` | PB8 / PB9 | 独立 GPIO 开漏软件 I²C，外部上拉仅为 3.3 V。 |
| JY61P | `SCL` / `SDA` | PB6 / PB7 | 独立 GPIO 开漏软件 I²C；电平、地址、协议待确认。 |
| ESP-01S | `RXD` / `TXD` | PA2 / PA3 | USART2 交叉收发：PA2→ESP RXD，ESP TXD→PA3。 |
| CH340N | `RX` / `TX` | PB10 / PB11 | USART3 交叉收发：PB10→CH340 RX，CH340 TX→PB11；当前程序仅输出调试信息，不接收控制命令。 |
| 按键 1/2/3 | `K1` / `K2` / `K3` | PB0 / PB1 / PA8 | GPIO 输入 + 内部上拉；配置为低有效（按下拉低）。已接入调试模式，见 §2.1。 |
| 运行指示灯 | - | PC13 | GPIO 输出；当前配置低有效，需实板核对。 |
| SWD | SWDIO / SWCLK | PA13 / PA14 | 保留调试，禁止改作业务 GPIO。 |
| 外部晶振 | OSC_IN / OSC_OUT | PD0 / PD1 | HSE 专用，频率/负载电容以实际板卡为准。 |

PB6/PB7、PB8/PB9 在本工程中均由软件 I²C 驱动，不可再同时由 STM32 硬件 I²C 外设接管。ESP 的 `RST/EN/IO0/IO2` 和 JY61P 的 RX/TX 没有给出 STM32 连线，固件不得虚构这些 GPIO/UART。

### 2.1 调试模式：板载按键映射（`CFG_DEBUG_BUTTONS_ENABLED`）

用途是**上位机暂时不可用时**在台架上直接验证执行器。开关默认 `1`，设为 `0` 即整体关闭（声明也不参与编译）。

| 按键 | 引脚 | 动作 |
| --- | --- | --- |
| `K1` | PB0 | 切换 M1 驱动：按一次开始转，**再按一次停止** |
| `K2` | PB1 | 舵机左转 `CFG_SERVO_SAFE_MIN_DEG`（**−15°**，脉宽 1750 µs） |
| `K3` | PA8 | 舵机右转 `CFG_SERVO_SAFE_MAX_DEG`（**+15°**，脉宽 1250 µs） |

实现要点：

1. 三个键低电平有效、内部上拉，按**按下沿**触发一次动作；去抖窗口 `CFG_BUTTON_DEBOUNCE_MS`（30 ms）。窗口内的抖动只算一次，不会连续切换。
2. `DebugButtonsInit()` 在 `App_Init()` 里以**真实电平**作为初值，所以上电时已经按住的键不会被当成一次"按下"。
3. 每次动作都往 USART3 打一行 `DEBUG K1 motor ON` / `DEBUG K1 motor OFF` / `DEBUG K2 servo LEFT` / `DEBUG K3 servo RIGHT`，便于事后核对执行器是谁在什么时候动的。
4. 本地动作走 `Motor_SetRunning()`，**不经过协议**，因此不占用序号窗口、不伪造远端命令。
5. **上位机始终优先**：任何被接受的远端 `CMD` 都会立刻覆盖本地动作（`ApplyAcceptedCommand`）。所以远端链路的失效保护也照常生效。

⚠️ **安全语义变化（必须知情）**：本功能有意放开"无链路即无运动"这条看门狗保证 —— `K1` 启动的转动在**完全没有上位机**时会一直持续，直到再按一次 `K1`。`Control_CheckTimeout()` 的失效保护只在"曾经有过一条被接受的命令"（`link_alive == true`）时才可能触发，因此纯本地调试不会有任何看门狗兜底。**下水前必须把 `CFG_DEBUG_BUTTONS_ENABLED` 设回 `0`。**

排障：若按键完全无反应，先看串口有没有 `DEBUG …` 输出。有输出而执行器不动 ⇒ 查执行器侧；没有输出 ⇒ 多半是极性判断反了（把 `CFG_BUTTON_ACTIVE_LOW` 改成 `0`）或按键未接地。静止时若出现**自发的** `DEBUG …` 行，说明该引脚浮空或被误判为按下。

## 3. TB6612 与两路直流减速电机

TB6612FNG 是**双全桥直流电机驱动**。现在它的两个桥各驱动一台有刷直流减速电机：

```text
TB6612 A01/A02 (M1) ——— 370 直流减速电机（主推进，带动鱼尾）
TB6612 B01/B02 (M2) ——— N20 直流减速电机（12V 版本，驱动唧筒活塞）
```

**PWM 是直流电机的标准调速手段，不是"步进专用"**：`VM` 接 12 V，电机两端得到的是「12 V × 占空比」的平均电压。当前满速挡为 **95% 占空比**（≈11.4 V），低速挡为 **60%**（≈7.2 V）；两路共用同一挡位。

`motor_control.c` 只做「一条命令 → 两个 H 桥的 IN1/IN2 与占空比」，没有换相节拍、没有 STEP/DIR、没有位置闭环。

### 3.1 两路独立配置

| 配置 | 默认值 | 作用 |
| --- | --- | --- |
| `CFG_MOTOR_A_ENABLED` / `CFG_MOTOR_B_ENABLED` | `1` / `1` | 每路独立使能；设为 0 时该路只 coast，另一路不受影响。 |
| `CFG_MOTOR_FULL_DUTY_PERCENT` | `95` | **满速挡**占空比，范围 1–100。 |
| `CFG_MOTOR_LOW_DUTY_PERCENT` | `60` | **低速挡**占空比，范围 1–100，且不得大于满速挡。 |
| `CFG_MOTOR_A_DUTY_PERCENT` / `CFG_MOTOR_B_DUTY_PERCENT` | 缺省 = 满速挡 | 可选覆盖：给单路固定一个占空比；不定义时随挡位走。 |
| `CFG_MOTOR_TIM_PRESCALER` / `CFG_MOTOR_TIM_PERIOD` | `7199` / `19999` | TIM2 分频与自动重装值，合起来给出 **2 s 周期**（有编译期一致性校验）。 |
| `CFG_MOTOR_PWM_PERIOD_MS` | `2000` | 名义周期（ms），与上面两项互为校验。 |
| `CFG_MOTOR_STBY_PIN_ENABLED` | `0` | 置 1 后固件在 PB5 推挽输出并拉高 STBY；实物 STBY 恒接高时保持 0。 |

占空比是**开环电压设定，不是限流**：TB6612 数据手册只给热关断与低压检测，**没有过流/短路保护规格**。

### 3.2 已知电气条件

用户已确认 VM 为约 12 V，来自 45C、3S 航模锂电池；**STBY 已接高电平**。电机没有铭牌，额定电流仍未知。370 与 N20 的减速比、空载转速与堵转电流都必须在实物上量。

本轮采用**满速挡 95% / 低速挡 60%**运行：这是"开环调压"设定，**不是恒流限制也不是过流保护**。TB6612 的 1.2 A/通道是绝对最大额定值，3.2 A 仅为 10 ms 单脉冲条件，不能据此认定可持续。堵转电流与温升必须在实物上观察。

### 3.3 为什么是「2 s 慢周期 + 95%」而不是「20 kHz + 100%」

**问题现象**：VM = 12 V、STBY 已拉高，电机仍带不动负载。

**根因**：原配置用 100% 占空比，在 STM32F1 上落成 `CCR = ARR + 1`，比较输出**恒为高电平、永不翻转**。TB6612 的 PWM 输入依赖持续的开关边沿来维持高侧栅极/自举驱动；只给一根恒定的高电平，自举电容得不到刷新，高侧开关无法持续导通 → 电机只有微弱/断续的驱动能力，带载即掉。

**修正**：
1. **降占空比到 95%**：保证每个载波周期都有一次完整的低电平沿。95% × 12 V = 11.4 V，转速与扭矩相对满压几乎无损。
2. **载波周期改为 2 s**：用户明确要求"2 s 一周期、满速满扭驱动"。周期拉长后低速挡的"慢转"效果与占空比解耦得更干净，也便于用示波器/万用表直接观察一个周期的边沿。

**配套改动**：`SetBridgeCompare()` 不再等待定时器自然更新（周期改成 2 s 后，等待自然更新最多会阻塞 2 s），改为写入 CCR 后立即发一次 `HAL_TIM_GenerateEvent(&htim2, TIM_EVENTSOURCE_UPDATE)` 强制影子寄存器提交，命令延迟回到毫秒级。

**边界**：如果后续实测证明 TB6612 在恒高输入下也能稳定驱动（即根因判断有误），把 `CFG_MOTOR_FULL_DUTY_PERCENT` 改回 100 即可，其余逻辑不变；但慢周期会随之让"100% = 恒高、无开关动作"这一点更突出，改动前先用示波器确认模块的实际行为。

### 3.4 STBY 与 coast 语义

TB6612 的 STBY 现在有两种接法：

- **实物接法（当前）**：STBY 恒接高电平，模块始终使能。软件只能靠 IN1/IN2 实现 coast，无法整片关断。`CFG_MOTOR_STBY_PIN_ENABLED` 保持 `0`。
- **可选软件接法**：把 STBY 改接到 PB5 并把开关置 `1`，固件会在启动 PWM 前推挽输出拉高 PB5。这给了一条"整片禁用"的排障通路，但**不是必须项**，默认关闭以免占用 PB5 并改变既有硬件行为。

**软件 coast 为无励磁停止，不等于切断 VM 供电。** 真正的断电只能靠电源开关或（启用后）拉低 STBY。

## 3.5 ESP-01S 的 Wi-Fi 模式必须是「纯 AP」（2026-09-23 回归修复）

`CFG_ESP_WIFI_MODE` 控制 `SET_MODE` 下发的 `AT+CWMODE` 值，**必须为 `2`（仅 SoftAP）**。

| 取值 | 含义 | 可用性 |
| ---: | --- | --- |
| `2` | 仅 SoftAP | ✅ **当前选定值**，与 v0.5 之前写死的行为一致 |
| `3` | AP + STA 并存 | ❌ **不可用**：固件从不下发 `AT+CWJAP`，STA 侧永远拿不到凭据 |

**为什么 `3` 会让网页打不开**：`AT+CWMODE=3` 要求模块同时维持 AP 与 STA，但固件从不发 `AT+CWJAP`，STA 侧永远拿不到 SSID/密码。ESP-01S 于是反复去连 flash 里残留的旧 AP，落成 `sta=0.0.0.0`；双模下模块（仅 1 MB flash）还要同时维护 AP 的 DHCP 服务器与 `CIPSERVERMAXCONN` 个 socket 槽位，内存紧张，最终导致客户端拿不到 IP、AP 转发失效 ⇒ 手机连上了热点但 `192.168.4.1:9000` 打不开。

**回归的来历**：v0.5 之前的版本（提交 `9b97230`）**根本没有这个宏**，`SET_MODE` 写死 `AT+CWMODE=2`，所以网页一直正常。v0.5（`f30f511`）引入该宏时默认写成了 `3`，同时新增了 `SET_CHECK_STA_IP` 步骤，这就把一直可用的纯 AP 配置破坏掉了。**若将来要重新启用 `3`，必须同时实现 `AT+CWJAP` 下发**，否则 `3` 永远是坏配置。

**验证方法**：USART3 的 `ESP` 诊断行里 `sta=` 字段。纯 AP 模式下为 `0.0.0.0` 属**正常**（没有 STA 地址）；`server=1` 表示 9000 端口已在监听；`error=OK` 表示 AT 通信正常。也可反汇编确认常量：`arm-none-eabi-objdump -d bionic_fish.elf | grep -A1 "8001c12:"`，纯 AP 应看到 `movs r3, #2`。

## 4. 舵机、OLED、JY61P 与通信电平

PA6 只输出舵机脉冲。**2026-09-23 起安全行程由 ±30° → ±20° 再收窄为 ±15°**：限幅用 `CFG_SERVO_SAFE_*`（**±15°**），而脉宽换算基准仍是 `CFG_SERVO_FULL_SCALE_DEG=30`（1000–2000 µs 的电气满量程）。因此 ±15° 只给出**满量程 1/2 的偏移**：左 −15° → 1750 µs、右 +15° → 1250 µs、0° 仍是 1500 µs，**不再出现 1000/2000 µs 端点**。实际机械中位、行程、输入阈值和 5 V 舵机电源的共地方式仍待实测。舵机若不能可靠识别 3.3 V 高电平，应使用经验证的单向电平转换，禁止将 5 V 回灌至 PA6。

**方向约定**：固件在与上位机对接的那一层把角度取反（`angle = -angle`），所以网页/协议侧只需按"左 = 正、右 = 负"的直觉下发，最终脉宽方向由固件统一保证。**极性反转只允许存在于一层**——本轮修正时发现网页端与固件端各反了一次、相互抵消成"网页左键实际右转"，已把网页端的映射改回与固件一致。

SSD1306 的 VCC 与 I²C 上拉均为 3.3 V。`ssd1306.c` 通过固定缓冲分块发送，`oled_ui.c` 在主循环中推进刷新。本工程使用原单页 ASCII 状态界面，未移植 `oled-ui-astra`，本轮不改页面布局。

JY61P 的 VCC1 标为 5 V 时，必须额外确认其 SDA/SCL 是否被上拉到 5 V。若是，PB6/PB7 会超出允许输入电平，需要双向 I²C 电平转换或经模块手册确认的上拉方案。还必须确认 I²C 模式、7 位地址、寄存器映射、字节序和校验；不得把 JY61P 的 UART 数据帧照搬为 I²C 寄存器协议。软件会进行 ACK、超时、总线恢复与相邻样本合理性检查，但不能修复错误电平或错误协议。

PB6/PB7 出厂没有板载上拉，开漏输出模式下 STM32 也无法启用内部上拉，因此 **PB6/PB7 必须外接 4.7 kΩ 上拉到 3.3 V**。这与 SSD1306 模块不同：多数 OLED 模块自带板载上拉，所以"屏能显示、IMU 读不到"不能直接归因于 JY61P 地址或寄存器。

### 4.1 JY61P 现阶段的诊断输出（UART3，115200 8N1）

固件在调试口给出下列判据，用串口助手即可区分故障类别。`scl=`/`sda=` 是**主机已释放**后读回的实际电平：开漏输出写 1 不再驱动总线，此时仍读回 0 只能来自外部（上拉缺失、被从机拉住、模块未供电或接线错）。

| 输出 | 含义 |
| --- | --- |
| `I2CBUS oled scl=1 sda=1 imu scl=1 sda=1` | 上电空闲电平正常，两条总线都能被外部上拉拉高。 |
| `IMUSCAN 0x50` | JY61P 总线（PB6/PB7）上 0x50 应答，地址与器件在位。 |
| `IMUSCAN none` | 整轮 0x08..0x77 无应答。每 2 s 重扫一轮。 |
| `IMU scl=1 sda=1 st=OK probe=1 fail=0 n=… e=0 raw=…` | 采样正常。`raw` 为最近一次成功读取的 6 个原始字节（roll/pitch/yaw 各 int16 小端）。 |
| `IMU scl=1 sda=1 … st=NACK` | 电气正常但器件不应答该地址/寄存器：地址或寄存器映射与实物不符。 |
| `IMU scl=0 sda=1 …` 或 `scl=1 sda=0 …` | 只有一条线为低。主机在错误路径上已保证释放，因此该低电平来自外部：接反、短路、或从机在事务中途拉住 SDA。 |
| `IMU … pu=11` | 只有总线不空闲时才会出现。把 PB6/PB7 临时切成内部上拉输入后两条线都能读回高 → **线路上没有任何东西在拉低，低电平是高阻线路"记住"的**，即外部 4.7 kΩ 上拉缺失。加电阻即可，与 JY61P/JY901S 型号、地址、寄存器都无关。 |
| `IMU … pu=10` / `pu=01` / `pu=00` | 内部上拉被外部拉低压住 → 有器件或短路在拉低，按接线/短排查。 |
| `IMU … n=… e=…` | `n` 为累计采样尝试，`e` 为累计失败。`e` 持续等于 `n` 说明从未读到过数据。 |

`I2CSCAN`（OLED 总线，PB8/PB9）与 `IMUSCAN`（JY61P 总线，PB6/PB7）是两条独立总线，互不代表对方的结论。

### 4.2 已测到的实板现象与定论（2026-09-10，实物为 JY901S）

烧录本版固件后，UART3 实测：

```text
I2CBUS oled scl=1 sda=1 imu scl=1 sda=1   ← 上电：两条总线都空闲为高
I2CSCAN 0x3C                               ← OLED 总线正常，屏认到了
IMUSCAN none                               ← PB6/PB7 上没有任何地址应答
IMU scl=0 sda=0 pu=11 st=STUCK probe=0 fail=… n=… e=… raw=-- R=NA P=NA Y=NA
```

**定论：PB6/PB7 没有外接上拉电阻。**

推理链：

1. OLED 总线（PB8/PB9）端到端可用（`I2CSCAN 0x3C`，`err` 无 bit7）；同一份 `soft_i2c.c` 驱动两条总线，所以驱动逻辑、时序、ACK 判定都不是原因。
2. `soft_i2c.c` 现在在**每个**错误路径上显式释放两条线（`ReleaseBothLines`），主机不会把线留在低电平。
3. 尽管主机已释放，`scl`/`sda` 仍稳定读回 0 —— 说明不是主机驱动的。
4. `pu=11`：把 PB6/PB7 临时切成**内部约 40 kΩ 上拉输入**后，两条线立刻都读回高。若线路上真有器件或短路在拉低，40 kΩ 内部上拉是抢不过它的。**因此线路上没有东西在拉低，低电平纯粹是高阻线路在主机驱动过一次之后"记住"的。**

这正是缺上拉的典型表现：上电瞬间线路尚未被驱动过，可读回任意值（实测为高）；一旦主机把它拉低一次，引脚电容上的电荷没有泄放/充电通路，就永久停在低电平，之后每次事务都必然失败。

**修复：在 PB6 和 PB7 上各加一只 4.7 kΩ 电阻到 3.3 V**（SDA、SCL 各一只，共两只）。这是正解，但不便立刻加电阻时可以先走 §4.4 的台架兼容模式。

其余需要一并核对的接线项：

1. JY901S 的 **VCC 与 GND 是否真的接通**，且与 STM32 共地。

#### OLED 黑屏（`err` 含 bit7 = 128）的同一套判据

`BF_FAULT_OLED_I2C` 置位说明屏没有完成初始化或整帧刷新。先看开机那行 `I2CBUS oled scl= sda=`：

| 输出 | 含义 |
| --- | --- |
| `oled scl=0 sda=1`（或反过来） | 该线在**主机已释放**时仍为低，只能是外部拉低：接线短到 GND、插针弯折搭到相邻脚、模块未供电被钳位。 |
| `oled scl=0 sda=0` | 两条线都被外部拉低，同上，优先查模块供电与共地。 |
| `oled scl=1 sda=1` + `I2CSCAN 0x3C` | 电气正常且屏应答，问题在初始化时序或模块本身。 |
| `oled scl=1 sda=1` + `I2CSCAN none` | 电气正常但无应答：换 0x3D、查模块型号/供电。 |

关键点：`SoftI2c_Init` 在读到这行之前已经对两条线写过 1（开漏释放），所以这时的低电平**不是主机造成的**。（2026-09-10 实测 OLED 黑屏时为 `oled scl=0 sda=1` + `I2CSCAN none`，与 JY61P 总线同一类外部拉低故障。）
2. 是否误接到模块的 **TX/RX（串口侧）**而不是 **SCL/SDA（I²C 侧）**；JY901 系列的串口与 I²C 是两组独立引脚。
3. 断开后量 **SCL–SDA、SCL–GND、SDA–GND** 是否短路（`pu` 已排除这一项，但接线时值得一并确认）。

### 4.4 无外部上拉时的台架兼容模式（`CFG_JY61P_INTERNAL_PULLUP`）

**现状：该开关默认 = 1，已在实板跑通。** 2026-09-10 实测输出：

```text
I2CBUS oled scl=1 sda=1 imu scl=1 sda=1 ipu=1
IMU scl=1 sda=1 pu=-- st=OK probe=1 fail=0 n=119 e=0 raw=46033BFF5323 R=4.6 P=-1.0 Y=49.6
<STA,...,roll=4.6,pitch=-1.0,yaw=49.7,err=35>
```

原始字节与解算一致，说明地址 `0x50`、起始寄存器 `0x3D`、小端字节序和 `raw/32768*180` 全部与 JY901S 实物相符：`4603`→838→4.6°、`3BFF`→−197→−1.0°、`5323`→9043→49.7°。

原理：STM32F1 的开漏输出模式忽略 PU/PD 位，"开漏 + 内部上拉"不可兼得。兼容模式改为在两种引脚状态之间切换：

| 总线动作 | 标准模式（`=0`） | 兼容模式（`=1`） |
| --- | --- | --- |
| 释放（线为高） | 开漏输出写 1（高阻，靠外部上拉） | `GPIO_MODE_INPUT` + `GPIO_PULLUP`（内部约 40 kΩ 充电） |
| 拉低 | 开漏输出写 0 | 切回 `GPIO_MODE_OUTPUT_OD` 后写 0 |

代价与边界：

- 每个边沿多一次引脚模式写入，位周期变长、总线变慢。`ClockHigh` 本来就是"等到线真的变高再延时"，所以只降速、不破坏时序正确性。
- **内部上拉只有约 40 kΩ**，边沿上升约 3 µs 量级，抗 EMI 能力远弱于 4.7 kΩ。**只适合台架验证姿态数据，不适合带电机/水下的整机运行。**
- 维特智能本身要求 I²C 走线 10 cm 以内，这条约束在兼容模式下更严格。
- 总线诊断中 `pu=` 字段在兼容模式下恒为 `--`：总线不空闲时探针不会触发（引脚本来就在用内部上拉）。

**焊上真正的 4.7 kΩ 上拉后，把 `app/Inc/app_config.h` 的 `CFG_JY61P_INTERNAL_PULLUP` 改回 `0`**，恢复标准纯开漏时序。该开关只作用于 JY61P 总线；OLED 总线（有板载上拉）始终使用标准开漏。

### 4.3 实物为 JY901S 而非 JY61P：对本工程无协议影响

用户于 2026-09-10 确认实物是 **JY901S**（9 轴，带磁力计与温补）。核对结论：

| 项目 | JY901S 与 JY61P 是否相同 | 说明 |
| --- | --- | --- |
| I²C 7 位地址 | **相同** | 均为 `0x50`（写 `0xA0`、读 `0xA1`）。 |
| 角度寄存器 | **相同** | `0x3D`/`0x3E`/`0x3F` = Roll/Pitch/Yaw，均 int16 先低字节后高字节。 |
| 读取方式 | **相同** | 从 `0x3D` 连读 6 字节；维特智能官方 IIC 例程对 JY61P/JY901/JY901S/JY901B 标注为同一套用法。 |
| 上拉要求 | **相同** | SDA/SCL 均需外接 4.7 kΩ～10 kΩ 上拉。 |
| 是否需上位机开启 I²C | **相同** | 均无需；标准协议模块上电即应答 I²C，I²C 是问答式、不主动推送。 |

**因此 `jy61p.c` 不需要任何改动**，当前 `CFG_JY61P_ADDR_7BIT=0x50`、`CFG_JY61P_ANGLE_START_REG=0x3D` 对 JY901S 同样成立。

真正需要注意的差异不在协议层，而在语义与布线：

1. **Yaw 含义不同。** JY901S 是 9 轴，Yaw 由磁力计给出绝对航向；JY61P 是 6 轴，Yaw 只是陀螺积分、会漂移。因此 `yaw` 字段在 JY901S 上是可用的绝对航向，但仍受机内电机/磁铁磁干扰影响，须实机核对。现有 `CFG_JY61P_MAX_DELTA_DDEG=900`（90°/50 ms）跳变筛选沿用，上台架按实际转动速率校准。
2. **布线长度是硬约束。** 维特智能明确说明 I²C 仅适用于板内短距离（建议 10 cm 以内），更长距离推荐改用串口。鱼体内部的走线必须压短。
3. 型号名的文档口径：本文件与 `README.md` 中原写"JY61P"的位置按实物读作 JY901S；`jy61p.*` 的文件名与 `CFG_JY61P_*` 宏名保持不变，避免改动面扩散。

ESP-01S 与 CH340N 均需交叉收发、3.3 V TTL 逻辑和共地。`STA.link=1` 只说明近期收到有效应用控制帧；没有 ESP 明确上报时，不表示 Wi-Fi、安卓或互联网一定在线。所有外部输入不得超过 3.3 V。

## 5. 建议实测记录

| 项目 | 应记录的证据 |
| --- | --- |
| 两路直流减速电机 | M1 = 370：额定电压/电流、堵转电流、减速比、空载转速；M2 = N20（**12V 版本**，唧筒）：额定电流、减速比，以及活塞行程两端的微动开关限位接线。 |
| TB6612 | A/B 输出对应、**STBY 实际接法（当前恒接高）**、VM/VCC、供电电流、温升、coast 真值表行为、EMI。 |
| 两路电机驱动 | 两路各自的前进/后退方向与机械方向是否一致、停止与失联行为、**2 s 慢周期 + 95% 占空比下能否稳定带载**、实际电流、堵转电流与 TB6612 温升。 |
| 舵机 | 3.3 V 识别、电源、中心脉宽、机械限位和 **±15° 实测角度（1750/1250 µs）**。 |
| OLED | 控制器、地址、上拉、电压、刷新稳定性和 I²C 错误恢复。 |
| JY61P | I²C 模式/地址/寄存器/校验、逻辑高电平、零偏、刷新率和断线恢复。 |
| ESP/CH340 | 电平、电源压降、串口误码、重连与状态帧连续性。 |

## 本轮资料核对（2026-09-09）

采购资料能确认曾采购 JY61P 成品和 CH340N。现有发票没有明确的 ESP-01S 记录，也没有步进电机额定参数；核心板商品名混列 C8/C6/CH32/GD32，不能单据此确认具体芯片。

`建模/42HS34-FS.STEP` 与装配截图属于**已作废的步进方案**，与当前两台直流减速电机无关，不要再据此推断额定电压/电流、步距角或减速比。当前配置只依赖 `CFG_MOTOR_FULL/LOW_DUTY_PERCENT`（95% / 60%）与 2 s 慢周期，而这两个值是否安全必须靠实测温度与电流判断。

## 用户提供的 ESP 版本回包

已收到用户通过串口提供的 `AT+GMR` 输出（不是本机自动采集）：

```text
AT version:1.7.4.0(Jul  8 2020 15:53:04)
SDK version:3.0.5-dev(52383f9)
compile time:Aug 28 2020 14:37:33
OK
```

该AT版本匹配当前 `esp_link.c` 的 NONOS 1.7.4 分支。`SDK version` 是底层SDK版本，不用于本工程的AT版本分支选择。先保留现有ESP固件，无需仅为版本匹配而重刷；Flash容量在需要重刷时再核对。

用户随后提供的串口查询为：

```text
AT+UART_CUR?
+UART_CUR:115273,8,1,0,1
OK
```

`115273` 是标称 115200 经分频后的实际波特率，当前驱动允许这一误差；`8,1,0` 为 8N1。最后的 `1` 表示 RTS 流控已开启，与本工程无 RTS/CTS 的接线配置不符。当前驱动会停在 UART 核查阶段并报告错误，不会将 TCP 服务标为就绪。

串口助手保持 115200、8N1、无流控，逐条发送并等待 `OK`：

```text
AT+UART_DEF=115200,8,1,0,0
AT+UART_CUR?
```

预期查询为 `+UART_CUR:115273,8,1,0,0`（约 115200、最后一项为 0）。`UART_DEF` 同时保存上电默认参数；单用 `UART_CUR=` 不会保存，STM32 启动时的 `AT+RST` 会恢复默认参数。设置后可发 `AT+RST`，等 `ready` 再查询以核对持久化结果。依据：[乐鑫 ESP8266 AT 指令集，UART_CUR / UART_DEF](https://www.espressif.com/sites/default/files/4a-esp8266_at_instruction_set_en_v1.5.4_0.pdf)。

用户已提供修正后的查询结果：

```text
AT+UART_CUR?
+UART_CUR:115273,8,1,0,0
OK
```

当前串口配置已匹配驱动要求；AT 版本与当前 UART 参数均已由用户回包确认。尚未记录复位后的复查结果，STM32 到 ESP 的通信和完整 TCP 握手仍需实板验证。

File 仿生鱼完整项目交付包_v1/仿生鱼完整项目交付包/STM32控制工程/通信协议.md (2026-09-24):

# 通信协议

## 1. 基本规则

协议用于安卓上位机经 ESP-01S → USART2 → STM32 发送控制命令，以及 STM32 经 USART2（回 ESP）和 USART3（CH340N）输出确认、错误和状态。它采用可打印 ASCII 与换行分帧，便于 APK 和串口工具调试；不提供加密、鉴权或传输层 CRC。

```text
<TYPE,key=value,key=value,...>\n
```

- 帧尾必须是 `LF`（`\n`）；接收端也接受 `CRLF`。
- 字段值不得包含 `<`、`>`、`,`、`=`、换行或 NUL。帧最大载荷为 `CFG_PROTOCOL_PAYLOAD_MAX-1`，当前为 191 字节。
- 组帧状态机在收到 `<` 后最多等待 `CFG_PROTOCOL_FRAME_TIMEOUT_MS`（当前 250 ms）。超时、超长、不可打印字符或错误 EOL 均丢弃并重新同步。
- UART 中断只接收字节至固定大小环形缓冲；完整帧在主循环解析。任何解析/语义/序号失败都不能造成部分电机或舵机动作。
- 未知但语法正确的 `key=value` 字段忽略，便于版本扩展；已知字段重复或缺失会拒绝整帧。

## 2. 控制帧：安卓 → ESP → STM32

```text
<CMD,seq=12,move=F,turn=R,step_speed=60,servo=-15,m2=R>\n
```

五个基础字段必填、`m2` 选填，顺序可任意：

| 字段 | 取值 | 含义与校验 |
| --- | --- | --- |
| `seq` | `0`~`65535` | 16 位无符号序号，用于重复、乱序和丢包检测。 |
| `move` | `F` / `R` / `S` | **M1（370 主推进）** 前进、反向、停止。2026-09-12 起换向已放开：`move=R` 不再返回 `E_STEP_REVERSE_UNSUPPORTED`。 |
| `turn` | `L` / `R` / `C` | 左、右、居中语义，必须与 `servo` 符号一致。 |
| `step_speed` | `60` / `100` | **占空比挡位选择器**：`100` = 满速挡（`CFG_MOTOR_FULL_DUTY_PERCENT`，当前 95%），`60` = 低速挡（`CFG_MOTOR_LOW_DUTY_PERCENT`，当前 60%）。仍必填且只接受这两个值；两路电机共用同一挡位。 |
| `servo` | `-15`~`15` | 相对中位角（度）；负值左、正值右。超出 ±15° 直接返回 `E_RANGE`（不再限幅接受）。 |
| `m2` | `F` / `R` / `S` | **选填**：**M2（N20 唧筒电机）** 活塞推、拉、停。**缺省 = 停止**（不是"保持原状态"）。V1.0.0 起该链路已实装，可正确驱动唧筒活塞改变排水量实现沉浮。 |

> `step_speed` 是历史字段名（旧步进方案用它选转速档）。字段名、取值范围和"必填"约束保持不变以兼容旧客户端，但自 2026-09-23 起它承载的是**直流电机占空比挡位**，不再是"步进速度"。

语义约束如下：

- `turn=L` 必须配负 `servo`，`turn=R` 必须配正 `servo`，`turn=C` 必须配 `servo=0`；不一致返回 `E_SEMANTIC`，不会静默选择其中一个。
- `move=S` 仍须携带合法的 `step_speed`，两路电机同时进入 coast，状态中的 `step_on=0`、`m1=S`。
- 默认 `CFG_MOTOR_A_ENABLED=1` / `CFG_MOTOR_B_ENABLED=1`，两路各以当前挡位的占空比持续运行。任一路被显式设为 0 时，针对该路的运动命令返回 `E_STEPPER_DISABLED`（错误码名沿用，位号与词表不变）。
- `move=R` 自 2026-09-12 起正常支持（直流减速电机由 IN1/IN2 直接换向）；原单向策略与 `CFG_STEPPER_UNIDIRECTIONAL` 已删除。

### 2.1 旧字段兼容性

旧客户端若仍附带 `n20_dir=...`、`n20_pwm=...` 等字段，它们作为未知扩展字段被解析器忽略，不会控制任何硬件，也不会出现在 `STA`。**M2 端现由 `m2=` 字段控制**（N20 唧筒已实装；作废的仅是旧的步进线圈接线方案）。

### 2.2 序号规则

| 条件 | 动作 |
| --- | --- |
| 首帧，或失联/溢出后新建会话 | 接受，建立序号窗口。 |
| `seq` 与最后成功帧相同且五个控制字段完全相同 | 视为幂等重传，不重复执行，回复 `ACK,DUP` 并刷新保活。 |
| 相同 `seq` 但载荷不同 | 拒绝，`E_SEQ_CONFLICT`。 |
| 模 65536 差值为 1~32767 | 视为新帧，接受；差值大于 1 会记录序号缺口。 |
| 差值为 32768 | 回绕歧义，拒绝，`E_SEQ_AMBIGUOUS`。 |
| 差值大于 32768 | 旧帧/乱序帧，拒绝，`E_SEQ_OLD`。 |

失联或 UART 接收溢出会清除序号窗口，使 ESP/安卓重启后能从新的 `seq` 重新建链。非法帧、语义拒绝帧和旧帧都不能刷新保活。

## 3. 状态帧：STM32 → ESP/CH340N

```text
<STA,seq=12,link=1,step_rpm=NA,step_est=NA,step_actual=NA,step_on=1,servo=-15,roll=1.2,pitch=-2.4,yaw=85.7,m1=F,m2=R,err=0>\n
```

状态帧按 `CFG_STATUS_PERIOD_MS`（当前 200 ms）周期发送，并在有效命令、失联或错误状态变化后由主循环持续反映最新状态。它可同时送往 ESP 与 CH340N；周期 `STA` 是低优先级，串口队列拥塞时不应阻塞控制或挤掉 `ACK/ERR`。

| 字段 | 含义 |
| --- | --- |
| `seq` | 最近一次成功提交的控制序号；未建链时应结合 `link=0` 判断。 |
| `link` | 最近收到了有效命令/幂等重传则为 1；这只表示应用控制链路新鲜，不证明 ESP Wi-Fi 或安卓连接真实在线。 |
| `step_rpm` | 固定为 `NA`；本轮无 RPM 目标控制。 |
| `step_est` | 固定为 `NA`；直流电机没有"每转步数"这一概念，也不做转速估算。 |
| `step_on` | `0`/`1`：**M1 是否处于运行**；恒等于 `(m1 != S)`。不证明机械轴实际转动。 |
| `step_actual` | 固定为 `NA`，因为本硬件没有编码器、霍尔或外部测速反馈。 |
| `servo` | 最终限幅后的相对中位角命令（范围 **±15°**），不等价于实际舵面反馈角。 |
| `roll` / `pitch` / `yaw` | JY61P 成功读取且有效时的姿态角；读不到/过期时为 `NA`，不能把 0.0 当作有效测量。 |
| `m1` | **新增**：M1 当前已下达方向，`F`/`R`/`S`（停止为 `S`）。旧固件不发送本字段。 |
| `m2` | **新增**：M2 唧筒当前已下达动作，`F`/`R`/`S`（推/拉/停，停止为 `S`）。旧固件不发送本字段。 |
| `err` | 当前活动故障位图的十进制值；不是最近一次协议错误字符串。 |

### 3.1 `STA.err` 故障位图

| 位 | 十进制值 | 名称 | 含义 |
| ---: | ---: | --- | --- |
| 0 | 1 | `BF_FAULT_LINK_TIMEOUT` | 有效控制帧超时或接收溢出后的强制断链。 |
| 1 | 2 | `BF_FAULT_ESP_RX_LOST` | ESP/USART2 接收缓冲溢出或 ORE 导致字节丢失。 |
| 2 | 4 | `BF_FAULT_IMU_DATA_TIMEOUT` | JY61P 姿态数据过期/不可用。 |
| 3 | 8 | `BF_FAULT_IMU_I2C_RECOVERY_FAILED` | JY61P 软件 I²C 总线恢复失败。 |
| 4 | 16 | `BF_FAULT_STEPPER_DISABLED` | 配置显式禁用该路电机输出（错误码名沿用旧方案）。 |
| 5 | 32 | `BF_FAULT_UART_TX_DROPPED` | UART 发送队列发生丢弃。 |
| 6 | 64 | 预留 | 保留，不用于任何旧电机功能；bit7/bit8 的位置不得前移。 |
| 7 | 128 | `BF_FAULT_OLED_I2C` | OLED 软件 I²C 运行期异常。 |
| 8 | 256 | `BF_FAULT_CONFIGURATION` | 关键配置或实际定时器初始化不一致。 |

多个故障可同时置位并相加，例如 `err=5` 表示链路超时（1）与 IMU 数据超时（4）同时存在。

## 4. ACK、错误帧与错误码

成功新命令与幂等重传的即时应答分别为：

```text
<ACK,seq=12,result=OK>\n
<ACK,seq=12,result=DUP>\n
```

错误帧示例：

```text
<ERR,seq=12,code=E_RANGE>\n
<ERR,seq=NA,code=E_FORMAT>\n
```

| 错误码 | 含义 |
| --- | --- |
| `E_FORMAT` | 定界、不可打印字符、EOL 等帧格式错误。 |
| `E_FRAME_TIMEOUT` | `<` 之后的半帧静默超过配置时间。 |
| `E_TOO_LONG` | 载荷超过固定缓冲限制。 |
| `E_TYPE` | 帧类型不是 `CMD`。 |
| `E_FIELD` / `E_DUP_FIELD` / `E_MISSING_FIELD` | 字段语法错误、已知字段重复或缺少五个必填字段。 |
| `E_RANGE` | 序号、枚举、挡位或舵机角度越界。 |
| `E_SEMANTIC` | `turn` 与 `servo` 的组合不一致。 |
| `E_SEQ_CONFLICT` / `E_SEQ_OLD` / `E_SEQ_AMBIGUOUS` | 相同序号内容不同、旧帧或回绕歧义。 |
| `E_STEP_REVERSE_UNSUPPORTED` | 默认单方向策略下请求 `move=R`。 |
| `E_STEPPER_DISABLED` | 配置显式禁用该路电机输出，固件保持该桥 coast。 |
| `E_CONFIGURATION` | 实际定时器配置与 `app_config.h` 不一致等关键配置故障。 |
| `E_RX_OVERFLOW` | UART 环形缓冲溢出/串口错误后，残帧已被丢弃。 |

协议错误用即时 `ERR` 告知；`STA.err` 只描述持续活动的运行期故障，二者不可混用。

## 5. 失联与溢出安全策略

超过 `CFG_LINK_TIMEOUT_MS`（当前 1000 ms）未收到有效命令/幂等重传时：

1. 两路电机始终停止，A/B 两桥均进入 coast，不保持未知电流；本交付不提供关闭失联停机的开关。
2. 舵机按 `CFG_SERVO_CENTER_ON_LINK_TIMEOUT` 处理；默认值为 1，回到中位。若改为保持，必须通过机械安全实测。
3. `link=0`，置 `BF_FAULT_LINK_TIMEOUT`，USART3 保持周期状态上报；主动关闭旧 TCP 连接，释放单客户端槽位。Android 重连后重新执行 STOP/ACK/STA 握手。

TCP 断开、ESP 重启或发送事务失败也会撤销控制会话。服务端固定配置 `CIPSTO=3` 秒空闲释放；应用已建会话的 1 秒控制超时独立主动关闭连接，不依赖 ESP 对空闲流量的具体判定。

ESP 接收环形缓冲溢出或 UART ORE 更严格：固件立即丢弃残余字节、重置解析器、清除会话和序号窗口、停止两路电机，并按配置回中舵机；不会等待普通的 1 秒保活超时。之后必须在可用的 TCP 连接上收到一帧完整、通过全部校验的 `CMD` 才能重新建链。连接已断开时 `E_RX_OVERFLOW` 只能通过 USART3 诊断观察，不能承诺已经失效的无线连接仍送达错误帧。

新安卓版本接受 RPM 的 `NA` 和 `step_on`；旧 0.3.1 APK 不支持该状态格式，必须安装本轮新版 APK。新安卓对旧数字 RPM 状态保持读取兼容。

## 6. 示例

默认配置下的低速挡连续前进请求（`step_speed=60` = 60% 占空比）：

```text
TX <CMD,seq=12,move=F,turn=R,step_speed=60,servo=-15,m2=R>\n
RX <ACK,seq=12,result=OK>\n
```

满速挡 + 舵机居中 + M2 也前进：

```text
TX <CMD,seq=13,move=F,turn=C,step_speed=100,servo=0,m2=F>\n
RX <ACK,seq=13,result=OK>\n
```

旧客户端携带无效功能字段时，五个必填字段仍正常，旧字段被忽略：

```text
TX <CMD,seq=14,move=S,turn=C,step_speed=60,servo=0,n20_dir=REV,n20_pwm=65>\n
RX <ACK,seq=14,result=OK>\n
```

最后一个示例只说明协议兼容性：`n20_dir` / `n20_pwm` 这类旧字段会被静默忽略，不驱动任何硬件。M2 端由 `m2=` 字段控制，接的是 TB6612 B 桥驱动的 N20 唧筒电机（V1.0.0 已实装）。

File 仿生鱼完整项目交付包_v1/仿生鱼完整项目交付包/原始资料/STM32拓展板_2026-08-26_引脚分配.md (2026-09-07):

# STM32 拓展板（2026-08-26）实际引脚接线

> 仅依据 `STM32拓展板_2026-08-26.epro2` 原理图中的 `PAD_NET` 和网络标号整理。

## 模块接线总表

| 模块 | 模块接口 | STM32 引脚 | 用途/说明 | 原理图网络 |
| --- | --- | --- | --- | --- |
| 运行指示灯 | LED | `PC13` | GPIO 输出 | `PC13` |
| TB6612 电机驱动器 | `PWMA`、`PWMB`、`AIN1/AIN2`、`BIN1/BIN2` | `PA0`、`PA1`、`PB12`、`PB13`、`PB14`、`PB15` | `PA0/PA1` 为两路 PWM；`PB12~PB15` 为两路电机方向控制 | 对应 GPIO 网络 |
| 电机端口 1 | `M1+`、`M1-` | 驱动器输出 | 电机功率端 | `M1+`、`M1-` |
| 电机端口 2 | `M2+`、`M2-` | 驱动器输出 | 电机功率端 | `M2+`、`M2-` |
| 舵机 1 | SIG | `PA6` | PWM/定时器输出 | `PA6` |
| 舵机 2 | SIG | `PA7` | PWM/定时器输出 | `PA7` |
| OLED 模块 | `GND`、`VCC`、`SCL`、`SDA` | `GND`、`+3.3V`、`PB8`、`PB9` | 四线接口；软件 I²C | `GND`、`+3.3V`、`PB8`、`PB9` |
| ESP-01S 模块 | `GND`、`VCC`、`RXD`、`TXD` | `GND`、`+3.3V`、`PA2`、`PA3` | `RXD` 接 STM32 `PA2`；`TXD` 接 STM32 `PA3`；`RST/EN/IO0/IO2` 悬空 | `GND`、`+3.3V`、`PA2`、`PA3` |
| USART1 接口 | RX、TX | `PA9`、`PA10` | `USART1_TX`、`USART1_RX` | `PA9`、`PA10` |
| USART3 接口 | TX、RX | `PB10`、`PB11` | 预留串口 | `PB10`、`PB11` |
| 按键 1 | 开关输出 | `PB0` | 低电平有效输入 | `PB0` |
| 按键 2 | 开关输出 | `PB1` | 低电平有效输入 | `PB1` |
| 按键 3 | 开关输出 | `PA8` | 低电平有效输入 | `PA8` |
| 下载调试接口 | SWDIO、SWCLK | `PA13`、`PA14` | SWD | `PA13`、`PA14` |
| 外部晶振 | OSC_IN、OSC_OUT | `PD0`、`PD1` | HSE | `PD0`、`PD1` |

## 模块接线方式

### TB6612

TB6612 的逻辑电源接 `+3.3V`、电机功率电源接原理图的 `+5V`，逻辑地和功率地均接 `GND`。具体信号为：`PWMA -> PA0`、`PWMB -> PA1`、`AIN1 -> PB12`、`AIN2 -> PB13`、`BIN1 -> PB14`、`BIN2 -> PB15`。两路电机输出分别接 `M1+ / M1-` 和 `M2+ / M2-`；电机端不得直接接 STM32 GPIO。

### JY61P 陀螺仪

JY61P 的 `VCC1` 接 `+5V`，`GND1` 接 `GND`；`SCL`、`SDA` 分别接 STM32 `PB6`、`PB7`（原理图网络标注为 `uart2`）。模块 `RX`、`TX` 接到独立的两针接口 `U3`，没有接入 STM32 引脚；`D0~D3` 也不是 STM32 通信引脚。

### OLED 屏幕

OLED 四线接口按 `GND -> GND`、`VCC -> +3.3V`、`SCL -> PB8`、`SDA -> PB9` 连接。

### ESP-01S

ESP-01S 按 `GND -> GND`、`VCC -> +3.3V`、`RXD -> PA2`、`TXD -> PA3` 连接，构成 USART2 交叉收发。`RST`、`EN`、`IO0`、`IO2` 在原理图中均未连接，不应误接到 STM32。

## 未连接 STM32 的网络

JY61P 的 `RX/TX` 仅连接到两针外部接口 `U3`，未连接 STM32；其 `SCL/SDA` 实际连接为 `PB6/PB7`，不属于未连接网络。

## 电源与共地

| 模块类别 | 电源 | 地 |
| --- | --- | --- |
| STM32、OLED、ESP-01S、逻辑接口 | `+3.3V`（以原理图标注为准） | `GND` |
| 舵机及电机驱动器 | `+5V` / `+12V` | `GND` |

所有模块必须共地；电机、舵机功率电源不得由 STM32 GPIO 直接提供。

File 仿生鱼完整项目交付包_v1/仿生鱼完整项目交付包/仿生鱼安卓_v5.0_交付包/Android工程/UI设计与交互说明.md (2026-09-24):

# v0.5.0 UI 设计与交互说明

采用 Kotlin、Jetpack Compose、Material 3、单 Activity 与导航；网络、协议、重连和完整控制目标均在 UI 外管理。

## 1. 页面与信息层级

| 页面 | 主内容 |
| --- | --- |
| 设备 | AP 热点直连常驻卡、系统 Wi-Fi 设置入口、LAN/Mock 发现、连接进度与错误。 |
| 控制 | 连接状态，M1/M2 独立方向组，±15° 舵机，回传状态和固定底栏双路急停。 |
| 状态/调试 | 两路固件方向、兼容 RPM（NA）、舵角、姿态、延迟、最后更新、故障与本地日志导出。 |
| 设置 | 独立 AP/LAN 参数、通信时序、两路反向开关、安全停止与减少动态效果。 |

## 2. 双电机与停止

- M1 标明“370 直流减速（主推进）”，M2 标明“N20（唧筒·沉浮）”；各有推、停、拉三个按键（推进侧即前进/停止/后退），不提供连续 PWM 或 RPM 滑杆。
- 挡位由 `step_speed` 承载：`60` = 低速挡（60% 占空比）、`100` = 满速挡（95% 占空比），来自配套固件的 2 s 慢周期双挡位方案；界面不将其当作测速结果。
- 单路按键仅修改一路，保留另一路及舵机目标；显式模式持续运行，松手即停模式松开只停当前一路。
- 底部“立即安全停止”始终可达，**不加阻碍紧急停止的二次确认**；同时停止 M1/M2，按配置回中或保留舵角，并显示 ACK 等待/失败状态。
- 导航离开、后台和断开按保存策略双停；重连不恢复旧方向。网络急停失败必须提示，不能把本地目标当成确认停机。
- 新安装允许两路反向；升级保留旧关闭偏好。关闭时按钮说明去设置启用并保存；保存关闭反向前先双停。
- 已取消旧步进参数确认对控制的阻挡；`stepperParametersConfirmed` 仅兼容存量状态，不再阻挡 M1 或 M2。

## 3. 舵机与状态

预设为左 -15°、中 0°、右 +15°；滑杆范围 -15..15，`steps=29`，共 31 个整数位置。拖动只更新本地预览，松手提交最终值；选中态与无障碍播报同步到 ±15°。

界面区分“本地目标”与“固件回传”：m1/m2 缺失为未知，非法值不刷新状态；step_on 仅 M1，不拿它推 M2。RPM/姿态 NA 明确标未知；超时显示数据过期。servo 是命令角，不是实际舵面传感器读数。接收旧 ±30° 状态不扩大新操控范围。

旧故障 bit4 解释为历史步进门禁；非零故障不等于解析失败，但必须保持可见。

## 4. 组件与无障碍

沿用 4dp 间距体系、浅/深色语义主题、按钮/方向组/滑杆/状态徽标/提示条/空状态；关键动作使用文字和状态语义，不只依赖颜色。

小屏通过自适应分组和滚动承载内容；底栏双停独立于内容滚动。关键控件至少 44dp 触控目标，支持系统 200% 字体。TalkBack 触摸探索开启时自动用显式停止，避免按住操作无法释放。减少动态效果配置不影响安全操作。

本版自动 UI 测试、模拟器截图及尺寸覆盖以 [构建验证报告](artifacts/v0.5.0构建验证结果.md) 为准。真实 S24、TalkBack 人工走查、完整横竖屏/平板、对比度测量和系统动画偏好仍待实测；未提供的 `UI设计RP.md` 不被宣称已逐条移植。

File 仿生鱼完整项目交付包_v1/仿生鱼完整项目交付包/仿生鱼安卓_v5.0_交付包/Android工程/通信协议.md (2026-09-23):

# v0.5.0 双电机通信协议

链路：Android → Wi-Fi TCP → ESP-01S → STM32。保留 V1 ASCII 协议，不增加未经固件支持的 HELLO/PING。本文固件行为来源为用户改造方案；实际板卡版本与动作待联调确认。

## 1. 帧格式

```text
<TYPE,key=value,...>\n
```

`\n` 表示实际 LF 字节 0x0A，接收兼容 CRLF。有效载荷最大 191 字节；流式接收支持粘包、拆包、半帧超时及重新同步。未知字段忽略，重复字段、非法数值、错误结束符等拒收整帧，不提交部分状态。

## 2. 控制 CMD：完整目标

```text
<CMD,seq=12,move=F,turn=L,step_speed=60,servo=-15,m2=R>\n
```

| 字段 | 值 | 语义 |
| --- | --- | --- |
| seq | 0..65535 | 新命令递增，允许回绕；幂等重传保留原序号。 |
| move | F / R / S | M1（370）前进 / 后退 / 停止。 |
| turn | L / R / C | 必须分别对应 servo 负值 / 正值 / 0。 |
| step_speed | 60 / 100 | 旧兼容字段；UI 固定发送 60，不影响配套直流固件占空比。 |
| servo | -15..15 | 目标角度，度；模型越界拒绝，UI 先限幅。 |
| m2 | F / R / S | M2（N20）前进 / 后退 / 停止；新 APK 每帧发送，位于 servo 后。 |

固件兼容的旧 CMD 缺少 m2 时，M2 **停止**，不是维持原方向。M1、M2 和舵机同时构成完整目标；修改一路时必须带上另一路和舵机的期望值。

安全停止（默认回中）：

```text
<CMD,seq=13,move=S,turn=C,step_speed=60,servo=0,m2=S>\n
```

若关闭安全停止回中，两路仍显式 STOP，只保留合法舵角与 turn。单路停止是高优先级完整目标，只把该路设 S；全局急停、默认后台/离页/断开停止为双 S。新安装默认允许两路 R；旧的关闭偏好保留，设置同时约束 M1/M2。

## 3. 状态 STA

```text
<STA,seq=12,link=1,step_rpm=NA,step_est=NA,step_actual=NA,step_on=1,servo=-15,roll=1.2,pitch=-2.4,yaw=85.7,m1=F,m2=R,err=0>\n
```

必填集合保持原 10 项：`seq/link/step_rpm/step_est/step_actual/servo/roll/pitch/yaw/err`。`step_on/m1/m2` 均可选，不因旧固件缺字段拒绝握手。

| 字段 | 接收行为 |
| --- | --- |
| m1 / m2 | F/R/S 转为独立方向；缺失为未知，其它值拒绝整帧。是已下达方向，不是实际机械反馈。 |
| step_on | 只能 0/1；仅表示 M1。缺失时可从旧的已知目标 RPM 推断 M1 运行；不能据此推断 M2 或具体方向。 |
| step_rpm / step_est | NA 或旧数字 0/60/100；NA 保持未知，不能填成 0。 |
| step_actual | NA 或有限数值；新固件没有编码器，不制造实际转速。 |
| servo | 接收单独保留 -30..30 兼容旧状态；**发送仍严格 ±15**，不据接收值扩大操控范围。 |
| roll / pitch / yaw | 有限数字或 NA，单位度；姿态与舵机命令角分开显示。 |
| link / err | link 为 0/1；err 为非负十进制位图。非零 err 是合法 STA，但不意味着硬件健康。 |

## 4. ACK、ERR、握手与时间

```text
<ACK,seq=12,result=OK>\n
<ACK,seq=12,result=DUP>\n
<ERR,seq=12,code=E_RANGE>\n
```

握手发送双停 CMD，要求同序号 ACK（OK/DUP）及 `link=1` 合法 STA。等待过程中每 400 ms 重发同一内容和序号，不添加第二个 ACK 等待器；完成、失败、取消均停止该保活任务。先等 ACK 默认 800 ms，再保留 STA 默认 2000 ms 窗口，不将全过程说成固定 2 秒。

| 参数 | 默认值 |
| --- | ---: |
| 运动目标发送 / 停止保活 | 200 / 500 ms |
| TCP 连接超时 | 5000 ms |
| ACK / 应用失联 / 遥测过期 | 800 / 1000 / 1200 ms |
| 重连间隔 / 最大次数 | 1000 ms / 3 次 |

控制与保活周期可配 50..750 ms；ACK 可配 100..900 ms 且短于失联阈值。周期发送完整 CMD 保活；重连从双停握手开始，不恢复断线前运动。发送与 ACK 等待不阻塞 UI，安全停止优先于普通排队命令。

## 5. 错误与兼容

`E_RANGE`：方向/舵角等非法；`E_DUP_FIELD`：重复字段；格式错误可返回 `E_FORMAT`。其它合法 `E_*` 原样展示。旧固件的 `E_STEP_REVERSE_UNSUPPORTED`、`E_STEPPER_HW_UNCONFIRMED` 仍按错误处理，不能伪报执行成功。

故障位沿用：bit0 链路超时，bit1 ESP RX 丢失，bit2 姿态超时，bit3 IMU I²C，bit4 **旧步进门禁（新双电机不用）**，bit5 UART TX 丢弃，bit6 保留，bit7 OLED I²C，bit8 配置异常；未知位保留显示。bit4 不再拦截新版直流电机 UI。

新 APK 对无 m1/m2 的旧 STA 显示未知；旧固件可能忽略 m2 或拒绝反向，不保证双电机可用。旧 APK 的 ±30° 命令会被 ±15° 新固件拒绝。四向真实硬件兼容矩阵尚未执行；本机仅协议/Mock 回放，不替代烧录版本核对。

应用尽力发停止，链路断开时无法保证送达。用户方案称固件 1000 ms 无有效 CMD 会双停并关闭旧 TCP；实际时间与舵机回中必须板上验证。本次没有改固件/网页，系统级 ±15° 需要配套确认。

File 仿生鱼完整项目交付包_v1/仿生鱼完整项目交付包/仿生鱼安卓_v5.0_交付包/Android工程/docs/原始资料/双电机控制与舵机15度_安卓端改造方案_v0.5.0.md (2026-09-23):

# 安卓端改造方案：双电机控制 + 舵机行程 ±15°（目标 v0.5.0）

> **本文取代** 同目录下的 `双电机控制与舵机20度_安卓端改造方案.md`（那份写的是 ±20°，已过期）。
> **适用对象**：`仿生鱼安卓_v0.4.0_交付包/Android工程`（当前 `versionName 0.4.0` / `versionCode 6`）
> **建议目标版本**：`versionName 0.5.0` / `versionCode 7`
> **本轮仍只出方案，不改安卓源码。**
>
> 本文与固件源码逐条对应；所有行号均已实机核对过。

---

## 0. 一句话结论

安卓端要做三件事：

1. **协议层**：CMD 增加可选字段 `m2=`；STA 增加可选字段 `m1=` / `m2=`；**舵角上限由 30° 改为 15°**。
2. **UI 层**：操控台新增 M2 一组「前进 / 停止 / 后退」；舵机预设按钮与滑块刻度由 ±30° 改为 **±15°**（滑块 `steps` 同步由 59 改 29）。
3. **安全层**：安全停止必须**同时停两路**；反向开关的默认值需要放开。

---

## 1. 固件侧新增内容（事实基线，勿凭记忆改）

### 1.1 推进执行器换代：步进 → 两路直流减速电机

| 项目 | 变化 |
| --- | --- |
| 执行器 | 原「42 两相双极步进 + TB6612 双桥软件四拍换相」→ **M1 = 370 直流减速电机**（A 桥）、**M2 = N20 直流减速电机（12V 版）**（B 桥） |
| 换相 | 换相表、相序、每转步数、RPM 换算、换相周期**全部删除**；启停与换向只由 `IN1/IN2` 决定 |
| PWM 载波 | TIM2 周期由 20 kHz 改为 **2 s**（`CFG_MOTOR_TIM_PRESCALER=7199` / `CFG_MOTOR_TIM_PERIOD=19999`）。**原因见 1.1.1** |
| 占空比 | 两路共用同一挡位：**满速挡 95%**（`CFG_MOTOR_FULL_DUTY_PERCENT`）/ **低速挡 60%**（`CFG_MOTOR_LOW_DUTY_PERCENT`）。不再有各自的编译期固定值，`CFG_MOTOR_A/B_DUTY_PERCENT` 仅作可选覆盖 |
| 调速 | **上位机只能选挡位，不能连续调速。** 字段 `step_speed=60/100` 仍必填、仍校验取值，现在映射为占空比挡位：`100`→满速挡、`60`→低速挡 |
| 反馈 | 无编码器、无闭速、无位置闭环。`step_rpm` / `step_est` / `step_actual` 恒为 `NA` |

> ⚠️ 安卓端不要再把它当成"可调速的步进"来设计 UI。`step_speed` 不是历史废字段，而是**挡位选择器**——安卓端若要暴露"低速挡"，就发 `step_speed=60`，其余情况发 `100`。

#### 1.1.1 为什么改成「2 s 慢周期 + 95% 占空比」

2026-09-23 现场问题是：**VM = 12 V、TB6612 的 STBY 已接高，电机却带不动负载**。

根因是原 100% 占空比在 STM32F1 上落成 `CCR = ARR + 1`，TIM2 比较输出**恒为高、永不翻转**；而 TB6612 的 PWM 输入需要持续的开关边沿维持高侧栅极/自举驱动。恒定高电平使自举电容得不到刷新，高侧无法持续导通 → 驱动能力弱，带载即掉。

处置是两条一起上：**满速挡降到 95%**（保证每个周期有一次完整低电平沿；95% × 12 V = 11.4 V，转速扭矩几乎无损），**载波周期拉到 2 s**（用户要求"2 s 一周期、满速满扭驱动"，也便于用示波器直接观察边沿）。

> **这对安卓端没有协议影响**——安卓侧只发 `step_speed`，具体占空比由固件决定。但**文案要改**：`step_speed` 应描述为"满速挡 / 低速挡"，不要再写"不改变输出的兼容字段"。

### 1.2 CMD（安卓 → 固件）：新增可选字段 `m2`

```
<CMD,seq=12,move=F,turn=L,step_speed=60,servo=-15,m2=R>\n
```

| 字段 | 取值 | 必填 | 语义 |
| --- | --- | --- | --- |
| `seq` | `0`~`65535` | 是 | 序号窗口；`last_sequence + 1` 永远合法 |
| `move` | `F` / `R` / `S` | 是 | **M1（370 主推进）** 前进 / 后退 / 停止 |
| `turn` | `L` / `R` / `C` | 是 | 舵机方向语义，必须与 `servo` 符号一致（负=L、0=C、正=R） |
| `step_speed` | `60` / `100` | 是 | **占空比挡位选择器**：`100` = 满速挡（固件 95%）、`60` = 低速挡（固件 60%）；两路共用同一挡位 |
| `servo` | `-15`~`15` | 是 | 舵机目标角；**越界由固件回 `E_RANGE` 整条拒绝**（不夹紧） |
| `m2` | `F` / `R` / `S` | **否** | **M2（N20）** 前进 / 后退 / 停止；**缺省 = 停止** |

关键语义（三条都必须理解，否则会做出错误的 UI）：

1. **`m2` 缺省是"停止"，不是"保持不变"。** 固件在解析层**显式**写了 `command.m2 = BF_MOVE_STOP;`（`protocol/Src/ascii_protocol.c:117-119`）。原因很实在：`BF_MOVE_FORWARD` 的枚举值恰好是 `0`，如果依赖 `memset` 清零，老客户端不发 `m2` 时会被当成"**M2 前进**"。
2. **整条命令是一个完整目标，没有增量语义。** 每个被接受的 CMD 会同时决定 `M1`、`M2`、舵机三者。**安卓端每帧都必须把想保持的状态一并带上**——这就是 `m2` 缺省取"停止"的根本原因。
3. **`move=R` 已放开。** 以前会回 `E_STEP_REVERSE_UNSUPPORTED`，现在正常接受并真正驱动 A 桥反转。

### 1.3 STA（固件 → 安卓）：新增 `m1` / `m2`

```
<STA,seq=12,link=1,step_rpm=NA,step_est=NA,step_actual=NA,step_on=1,servo=-15,
     roll=1.2,pitch=-2.4,yaw=85.7,m1=F,m2=R,err=0>\n
```

| 字段 | 取值 | 说明 |
| --- | --- | --- |
| `step_rpm` / `step_est` / `step_actual` | 恒为 `NA` | 语义不变，仍表示"固件不声明转速" |
| `step_on` | `0` / `1` | **语义已收窄：表示 M1 是否在运行**，恒等于 `(m1 != S)`。**不代表 M2** |
| `servo` | `-15`~`15` | 当前舵角（限幅后的命令值，不是实际舵面反馈角） |
| `roll` / `pitch` / `yaw` | 数字或 `NA` | 不变 |
| `m1` | `F` / `R` / `S` | **新增**：M1 当前已下达方向；停止为 `S` |
| `m2` | `F` / `R` / `S` | **新增**：M2 当前已下达方向；停止为 `S` |
| `err` | 十进制位图 | 位定义不变 |

**兼容性要点**：`m1` / `m2` 是**追加**在 `err` **之前**的字段，v0.4.0 的全部字段原样保留、**位置也未变**。所以：

- 安卓解析器的 `required` 集合**必须保持原样 10 项**，**不要**把 `m1`/`m2` 加进去 —— 一旦加进去，连旧固件时 STA 会被判成 `MISSING_FIELD`，兼容性立刻破裂。
- `m1`/`m2` 缺失（旧固件）时按 `null` 处理，UI 显示"未知"而不是报错。
- **`step_on` 只反映 M1。** 要在界面上表达"哪一路在动"，必须自己从 `m1` / `m2` 推导，不能只看 `step_on`。

### 1.4 失联与安全语义

- **1000 ms 内没有有效 CMD**（含同序号幂等重传）→ **两路电机同时 coast**（M1、M2 都停），舵机按配置回中，并主动关闭旧 TCP。
- UART 丢字节、TCP 断开、发送事务失败会更早触发同一套停止处理。
- 非法 `m2` 值（如 `m2=X`）→ 回 `E_RANGE`，**整条命令被拒，且不改动任何执行器**。
- `m2` 字段重复出现 → `E_DUP_FIELD`。

### 1.5 舵机行程：±30° → ±20° → **±15°（本次变更）**

固件把"能转多远"（`CFG_SERVO_SAFE_MIN/MAX_DEG`）与"多少度对应满脉宽"（`CFG_SERVO_FULL_SCALE_DEG`）拆成了两个独立参数：

```c
/* app/Inc/app_config.h */
#define CFG_SERVO_FULL_SCALE_DEG   30     /* 换算基准：1000–2000 µs 名义对应 ±30° */
#define CFG_SERVO_SAFE_MIN_DEG     (-15)  /* ← 本次由 -20 改到 -15 */
#define CFG_SERVO_SAFE_MAX_DEG     15     /* ← 本次由  20 改到  15 */
```

这个拆分很重要：**收窄 `SAFE_*` 不是把 15° 撑满 1000–2000 µs，而是只给出满量程的 1/2 脉宽偏移**。所以机械转角是真的变小了，而不是只把标签从 30 改成 15。

---

## 2. 舵机 ±15° 的换算与跨端一致性

### 2.1 固件实际换算式（`control/Src/servo_control.c:17-41`）

中心 1500 µs，满量程 ±500 µs 对应 ±`FULL_SCALE_DEG`：

```
offset_us = 500 × |angle| / 30          （整数运算，向下取整）
（极性在 2026-09-11 已对调：请求角先取反再换算）
左舵（请求负角） → 1500 + offset
右舵（请求正角） → 1500 − offset
中位            → 1500
```

### 2.2 三代行程的脉宽对照（`FULL_SCALE_DEG` 始终为 30）

| 请求角 | 行程版本 | `offset` | 实际脉宽 | 说明 |
| --- | --- | --- | --- | --- |
| `0°` | 全部 | 0 | **1500 µs** | 中位不变 |
| `−15°` 左 | **本次 ±15°** | 250 | **1750 µs** | |
| `+15°` 右 | **本次 ±15°** | 250 | **1250 µs** | |
| `−20°` 左 | 上一版 ±20° | 333 | 1833 µs | 仅旧固件会有 |
| `+20°` 右 | 上一版 ±20° | 333 | 1167 µs | 仅旧固件会有 |
| `−30°` 左 | 初版 ±30° | 500 | 2000 µs | 电气满量程端点 |
| `+30°` 右 | 初版 ±30° | 500 | 1000 µs | 电气满量程端点 |

**要点：±15° 时不再出现 1000 / 2000 µs 端点，最大只到 1250 / 1750 µs，机械余量更足。**

### 2.3 ⚠️ 只改安卓端并不足以让全系统变成 ±15°

这是最容易踩的地方，必须说清：

| 如果只改… | 实际效果 |
| --- | --- |
| 只改安卓端 UI 为 ±15 | 安卓发出的角在 ±15 内 ⇒ **物理上确实只转 15°**（固件是「角度→脉宽」直接换算，不会放大）。✅ 能达成效果 |
| 但固件 `SAFE_*` 仍是 ±20 | 固件仍**接受** ±20 的请求 ⇒ 别的客户端可以超过 15°，安全包络没真正收窄 ⚠️ |
| 且**网页端仍硬编码发 ±20** | `protocol/Src/http_ui.c:42` 的 `SM=20`，网页的「左舵 / 右舵」按钮会继续打 ±20 ⚠️ |

**结论：要让"全系统就是 ±15°"，必须安卓端 + 固件 + 网页三处一起改。** 三处的具体改动见第 6 节。

---

## 3. 安卓端文件级改动清单

路径均相对 `Android工程/`。

### 3.1 `app/src/main/java/com/bionicfish/controller/protocol/ProtocolModels.kt`

| 位置 | 改动 |
| --- | --- |
| `ControlCommand` data class | 新增 `val motor2: Move = Move.STOP`。**必须显式给默认值 `Move.STOP`** —— `Move.FORWARD` 是枚举第一项，容易踩 0 值坑（与固件同一个坑） |
| `ControlCommand.SERVO_RANGE`（L19） | `-30..30` → **`-15..15`** |
| L13 的 `require` 文案 | `"servo 必须在 -30..30"` → `-15..15` |
| L31 的 `require` 文案 | `"舵机角度超出 -30..30 度"` → `-15..15` |
| `ControlInput` data class | 新增 `val motor2: Move = Move.STOP` |
| `ControlInput.validated()` | 判断本身不用改，`servoDegrees in ControlCommand.SERVO_RANGE` 会自动跟随 |
| `ProtocolFrame.Status` | 新增 `val motor1Direction: Move? = null` 与 `val motor2Direction: Move? = null`（`null` = 固件未上报，即旧固件） |

### 3.2 `app/src/main/java/com/bionicfish/controller/protocol/AsciiProtocol.kt`

**编码**（`encodeControl`）：在 `servo=` 之后追加 `m2=`：

```kotlin
append(",servo=")
append(command.servoDegrees)
append(",m2=")
append(command.motor2.wireValue)
append(">\n")
```

**解码**（`parseStatus`）：

- `required` 集合**保持原样 10 项**，**绝不要**加入 `m1` / `m2`（原因见 1.3）。
- 新增可选解析：

```kotlin
val m1 = optionalDirection(fields["m1"])   // null = 旧固件未上报
val m2 = optionalDirection(fields["m2"])
```

- `optionalDirection` 语义：字段缺失 → `null`；`F/R/S` → 对应枚举；**其它值 → 整帧判 `Malformed(INVALID_VALUE)`**（与既有 `step_on` 的处理风格一致，不能让脏值静默变成"停止"）。

### 3.3 `app/src/main/java/com/bionicfish/controller/device/DefaultBionicFishRepository.kt`

| 位置 | 改动 |
| --- | --- |
| `ControlInput.toCommand()`（约 L931） | 透传 `motor2 = motor2` |
| `sendControl()`（约 L327） | 反向拦截当前只看 `input.move`，**必须同时覆盖 `input.motor2`**，否则 M2 反向会绕过设置项 |
| `sendSafeStopInternal()`（约 L673） | 安全停止**必须同时停两路**：`ControlInput.SAFE_STOP` 要带 `motor2 = Move.STOP`；**且 L684 那个"保留 turn/servo"的降级分支也必须显式写 `motor2 = Move.STOP`** |
| `ControlInput.SAFE_STOP` 常量 | 增加 `motor2 = Move.STOP` |

> ⚠️ **这一条是安全关键项。** 若安全停止漏写 `motor2`，一旦默认值或 `memset` 落在 `Move.FORWARD`，"停止"反而会把 N20 启动。必须专门写用例锁死。

### 3.4 `app/src/main/java/com/bionicfish/controller/control/BionicFishViewModel.kt`

| 位置 | 改动 |
| --- | --- |
| L227 | `requestedDegrees.coerceIn(-30, 30)` → **`coerceIn(-15, 15)`** |
| L247 | `servoDegrees = next.servoAngleDegrees.coerceIn(-30, 30)` → **`coerceIn(-15, 15)`** |
| `submitControl()` L242 | `ControlInput(...)` 增加 `motor2 = next.motor2.toDomain()` |
| 新增 `setMotor2()` | 与 `setMove` 对称：更新 `controlDraft.motor2` 后调用 `submitControl` |
| `UiActions` 装配（约 L108） | 新增 `onMotor2Changed = ::setMotor2` |
| `ControlUiState` 初始化 / `emergencyStop` | 紧急停止时把 `motor2` 一并置 `STOP` |

### 3.5 `app/src/main/java/com/bionicfish/controller/ui/model/AppUiState.kt`

| 位置 | 改动 |
| --- | --- |
| `ControlUiState`（L93） | 新增 `val motor2: MoveDirection = MoveDirection.STOP` |
| `UiActions`（约 L179） | 新增 `val onMotor2Changed: (MoveDirection) -> Unit = {}` |

`MoveDirection` 已有 `FORWARD / STOP / REVERSE`，直接复用，不必新建枚举。

### 3.6 `app/src/main/java/com/bionicfish/controller/ui/screens/ControlScreen.kt`

**舵机 ±15° 相关（共 11 处，注意有两处上一版方案遗漏了）**

| 行 | 现值 | 改为 |
| --- | --- | --- |
| L128 | `coerceIn(-30, 30)` | `coerceIn(-15, 15)` |
| L134 | `coerceIn(-30, 30)` | `coerceIn(-15, 15)` |
| L140 | `coerceIn(-30, 30)` | `coerceIn(-15, 15)` |
| L235 | `label = "左转 -30°"` | `"左转 -15°"` |
| L237 | `selected = ... == -30` | `== -15` |
| L240 | `onSteeringChanged(TurnDirection.LEFT, -30)` | `-15` |
| L247 | `label = "右转 +30°"` | `"右转 +15°"` |
| **L249** | `selected = ... == 30` | `== 15`　**（上一版方案遗漏）** |
| L252 | `onSteeringChanged(TurnDirection.RIGHT, 30)` | `15` |
| L309 | `raw.roundToInt().coerceIn(-30, 30)` | `coerceIn(-15, 15)` |
| L312 | `servoDraftDegrees.coerceIn(-30, 30)` | `coerceIn(-15, 15)` |
| L320 | `valueRange = -30f..30f` | **`-15f..15f`** |
| L321 | `steps = 59` | **`steps = 29`** |
| **L326** | `contentDescription = "舵机角度，范围负 30 度到正 30 度；松手后发送"` | `-15 ~ +15`　**（上一版方案遗漏，无障碍文案）** |
| L334 | `Text("-30° 左", ...)` | `"-15° 左"` |
| L336 | `Text("+30° 右", ...)` | `"+15° 右"` |
| L842（Preview） | `servoAngleDegrees = -30` | `-15` |

> **`steps` 必须同步改。** `Slider` 的 `steps` 是"中间刻度数"：`-30..30` 配 `59` 表示 61 个位置、步长 1°；改成 `-15..15`（跨度 30）后要配 **`29`** 才仍是步长 1°。写错会让拖动变成 1.5° 之类的非整数手感，而且很难察觉。

**新增 M2 控制卡片**

- 复用现有 `DirectionButton` / `AdaptiveChoicePair` 组件，与 M1 的"推进"区**完全对称**，避免两套交互手感。
- `enabled` 条件复用 `driveEnabled`（连接已建立 + `control.enabled`）。注意 `stepperParametersConfirmed` 这个门禁在固件侧已随参数确认机制删除，安卓端**保留字段但不要再拿它拦 M2**。
- 文案建议：M1 区标题 `主推进 M1（370 直流减速）`、M2 区标题 `N20 M2`，`supporting` 写明"两路独立，但上一条命令的两个目标会一起生效"。

**文案订正（顺带，属同类"步进口径"残留）**

- L169-170 `"固定低速推进"` / `"step_speed=60 仅用于兼容"` → 如实描述：`step_speed` 是**满速挡/低速挡选择器**（`100`=满速、`60`=低速），两路共用一个挡位。
- L415 / L421 / L696 `CommandMetric("推进模式", "固定低速")` → 改为显示 M1 / M2 两路方向 + 当前挡位（满速/低速）。
- 若要在界面上提供"低速挡"开关：勾选时 `step_speed=60`、否则 `100`；**注意这是两路共用的**，不要做成单路控件。

### 3.7 `app/src/main/java/com/bionicfish/controller/settings/AppSettings.kt`

- `allowReverseCommand` 当前默认 **`false`**（L42）。固件已支持换向，而 M2 的需求本身就是"正反转"，建议：
  - 默认值改为 **`true`**，UI 文案从"允许反向步进"改为"**允许电机反向（M1/M2 均生效）**"。
  - 字段名保留不改，避免 `SettingsStore` 迁移成本。
- **这是一项放开安全性的默认值变更，落地前请先确认。**

---

## 4. 兼容性矩阵（四向）

| 组合 | 结论 | 具体表现 | 验证方式 |
| --- | --- | --- | --- |
| **新 APK + 新固件** | ✅ 全功能 | 双电机独立启停/换向；舵机 ±15° | 真机 TCP 联调：发 `...&m2=R`，断言 STA 回 `m2=R`；发 `servo=-15` 断言 `1750 µs` |
| **新 APK + 旧固件**（±20° 版） | ⚠️ 降级可用 | `move`/`turn`/`servo` 照常；`m2` 被旧固件当**未知字段忽略** ⇒ **M2 不动**；±15° 落在旧固件的 ±20° 内 ⇒ 被接受；STA 无 `m1`/`m2` ⇒ APK 显示"未知" | 把新 APK 连旧固件，断言：CMD 不报错、M1 能动、M2 控件无效果、状态栏两路显示未知 |
| **旧 APK + 新固件** | ⚠️ 降级可用，**但有一处硬性不兼容** | 旧 APK 发 5 字段 CMD ⇒ 被接受，`m2` 缺省=停止（**安全**，不会误动 M2）；**但旧 APK 的 ±30° 预设会被新固件回 `E_RANGE`** | 固件侧已实测：无 `m2` 的 5 字段帧被接受且 M2 落停止；`servo=-30` 被回 `E_RANGE` |
| **旧 APK + 旧固件** | ✅ 原样 | 无变化 | 回归即可 |

### 4.1 唯一需要提前知会用户的破坏性变更

**交付的 0.4.0 APK 的「左转 -30° / 右转 +30°」按钮会被新固件拒绝**（`E_RANGE`），因为舵角合法区间已从 ±30° 收窄到 **±15°**。

这不是缺陷，是需求（"减小转角"）的直接后果。三个处置选项（**建议 A**）：

- **A（推荐）**：随固件一起发布新 APK，安装说明里写明"旧 APK 的 30° 按钮在新固件上会报错，请升级 APK"。
- **B**：固件侧把"越界"从**拒绝**改成**限幅**（夹到 ±15 而不是回 `ERR`）。改动很小，但会丢掉 `E_RANGE` 这层保护。
- **C**：不处理，让旧 APK 用户在 15°~30° 区间看到错误提示。

### 4.2 为什么"旧 APK + 新固件"不会误动 M2

因为固件把 `m2` 的缺省值在**解析层显式写成停止**，而不是依赖 `memset`：

```c
/* protocol/Src/ascii_protocol.c */
memset(&command, 0, sizeof(command));
/* m2 缺省必须是 STOP。BF_MOVE_FORWARD 的枚举值就是 0，不能依赖 memset：
 * 否则老客户端不发 m2 时会被当成「M2 前进」。 */
command.m2 = BF_MOVE_STOP;
```

安卓端在新代码里也有同一个坑（`Move.FORWARD` 是枚举第一项），见 3.1。

---

## 5. 测试影响清单

### 5.1 单元测试（`app/src/test/`）

| 文件 | 必改点 |
| --- | --- |
| `protocol/AsciiProtocolTest.kt` | L15 / L18 的 `servo=-30` → `-15`；L104、L239 等涉及 30 的断言同步；**新增**四组用例：① `m2=` 编码 ② `m1`/`m2` 状态解析 ③ **旧固件 STA（无 `m1`/`m2`）仍能解析且两字段为 `null`** ④ `m2=X` ⇒ `Malformed` |
| `device/DefaultBionicFishRepositoryTest.kt` | 多处 `servoDegrees = -30` → `-15`（L79/84/92/93/98/145/152/166/219/611 附近）；L105 `reverse stays blocked...` 语义要改（默认放开后反向应通过）；**新增**：双电机命令上链用例、**安全停止同时停两路**用例（断言 `move=S` 且 `m2=S`） |

### 5.2 仪器测试（`app/src/androidTest/`）

| 文件 | 必改点 |
| --- | --- |
| `ui/ControlScreenRenderTest.kt` | 渲染断言里的 30 → 15；新增 M2 三键的存在性与可达性断言 |
| `ui/BionicFishAppTest.kt` | 同上；若断言了"后退未启用"提示，需按 `allowReverseCommand` 新默认值调整 |
| `ui/ApDirectUiTest.kt` | 若涉及操控台控件枚举，补 M2 控件 |

### 5.3 兼容性专项测试（建议新增）

1. **旧固件 STA 回放**：用 `MockTransport` 注入一帧 v0.4.0 格式 STA（不带 `m1`/`m2`），断言解析成功、两个方向字段为 `null`、UI 不崩。
2. **旧 APK 命令回放**：用固件侧已有的 host 桩件发 5 字段 CMD，断言被接受且 M2 落停止。
3. **四向矩阵**：`{新APK,旧APK} × {新固件,旧固件}` 四格各跑一次"握手 → 前进 → 停止"。

---

## 6. 配套改动（**不在安卓端，但不做就会出现口径不一致**）

要做到"全系统统一 ±15°"，以下三处必须一起改：

### 6.1 固件：舵机安全行程

```c
/* app/Inc/app_config.h:111-112 */
#define CFG_SERVO_SAFE_MIN_DEG   (-15)   /* 原 -20 */
#define CFG_SERVO_SAFE_MAX_DEG   15      /* 原  20 */
```

`CFG_SERVO_FULL_SCALE_DEG` 保持 `30` **不要动** —— 动了就等于把 15° 撑满 1000–2000 µs，机械转角一点都不会变小。同时更新 L81-82、L108-110 的注释。

### 6.2 固件：宿主机测试的脉宽常量

```c
/* tests/host/Src/app_host_test.c:69-72 */
/* 左(-15 度) = 1500 + 250 = 1750us ；右(+15 度) = 1500 - 250 = 1250us ；0 度 = 1500us。 */
#define PULSE_LEFT_15DEG   1750U
#define PULSE_RIGHT_15DEG  1250U
```

`PULSE_LEFT_20DEG` / `PULSE_RIGHT_20DEG` 的引用点：L330、L412、L437、L644、L650、L750、L754、L759。断言逻辑本身不用改（它们比的都是 `CFG_SERVO_SAFE_MIN/MAX_DEG` 对应的脉宽），只需换常量与名字。

### 6.3 固件：局域网控制页的舵角幅度

```c
/* protocol/Src/http_ui.c:42 */
"<script>var m1='S',m2='S',sv=0,SM=20,tm=null,bs=0,er=0,"
                                       ↑ 改为 15
```

`SM` 就是网页「左舵 / 右舵」按钮发出的角度。不改的话，**网页仍会发 ±20°**。

> 顺带说明一处**有意保留**的行为差异：网页端 `/cmd?servo=` 与 `/servo?deg=` 走的是 `ClampServo()`，**越界会静默夹紧**；而 ASCII 协议 `servo=` 越界是**回 `E_RANGE` 整条拒绝**。同一个 `servo=-30`，网页能用、APK 报错。这是既有设计（网页是宽松的便利面），但文档里一直没写明，容易被误判成"网页限位失效"。

### 6.4 随包文档同步（**固件侧已于 2026-09-23 全部完成**）

| 文件 | 状态 |
| --- | --- |
| `STM32控制工程/README.md` | ✅ 已改：舵机 ±15；脉宽 1750/1250；载波 2 s；满速 95%/低速 60%；新 BIN 尺寸与 SHA-256（34,272 B / `517de91e…`） |
| `STM32控制工程/硬件引脚与驱动说明.md` | ✅ 已改：同上；新增 §3.3「为什么是 2 s + 95%」；§3.4 STBY 与 coast 语义；修 §3.2 标题重复与步进残留 |
| `STM32控制工程/通信协议.md` | ✅ 已改：`servo` ±15；`step_speed` 语义改为挡位；修 §6 示例里 `move=R` 的矛盾；修文末步进线圈残留 |
| `STM32控制工程/验收检查清单.md` | ✅ 已改：±15；新增「PWM 提交时序」「网页界面」「低速挡切换」等检查项 |
| `STM32控制工程/开发日志与修改清单.md` | ✅ 已追加 **附录 G（第六轮）**，含根因分析、改动清单、产物哈希、待实测项 |
| `Android工程/通信协议.md` | ⬜ **待改**：补 `m2` 字段行、`m1`/`m2` 状态字段行、舵角 ±15、`step_speed` 挡位语义、注明 `move=R` 已放开 |
| `Android工程/UI设计与交互说明.md` | ⬜ **待改**：补 M2 控制区、舵机行程 ±15、滑块步长说明、可选的低速挡开关 |
| `Android工程/验收检查清单.md` | ⬜ **待改**：新增"双电机独立控制""±15° 限幅""旧固件降级""低速挡切换"四行 |
| `Android工程/README.md` | ⬜ **待改**：版本号 → v0.5.0；说明本轮新增能力 |
| `先看这里_安装说明.md` | ⬜ **待改**：写明"0.5.0 APK 配套 0.5.0 固件；旧 APK 的 30° 按钮在新固件上会报错" |
| 本文档与旧的 `双电机控制与舵机20度_安卓端改造方案.md` | 旧文已标注被本文取代，建议从交付包移除或归档 |

---

## 7. 风险与未决项

| 级别 | 项目 | 说明 |
| --- | --- | --- |
| 高 | 旧 APK 的 30° 按钮被新固件拒绝 | 见 4.1，需产品决策 A/B/C |
| 高 | 安全停止漏带 `m2=STOP` | 会导致"停止"反而启动 N20。必须专门写用例锁死 |
| 高 | **实板带载驱动尚未验证** | 2 s 慢周期 + 95% 占空比是本轮针对"带不动"的修复，但**只有实板能证明有效**；若仍带不动需回看 §1.1.1 的根因判断 |
| 中 | **2 s 周期的边沿稀疏性** | 慢周期下平均电压建立慢，低速挡若出现"一顿一顿"，优先怀疑是慢周期而非驱动故障 |
| 中 | 只改安卓端不改固件/网页 ⇒ 全系统仍是 ±20° 包络 | 见 2.3。三处要一起改（固件与网页侧**本轮已改完**） |
| 中 | `allowReverseCommand` 默认值放开 | 安全性默认值变更，需确认 |
| 中 | `stepperParametersConfirmed` 门禁已无对应固件机制 | 固件侧已删除，安卓端保留字段但不要用它拦电机 |
| 中 | **TB6612 无过流保护 + 无实测堵转电流** | 满速挡（95% × 12 V）长期运行必须实测电流与温升 |
| 低 | 滑块 `steps` 忘记由 59 改 29 | 拖动步长会变成非整数手感 |
| 低 | `ControlScreen.kt` L249 / L326 两处遗漏 | 上一版方案已漏，会导致 `selected` 高亮错位、无障碍播报错误 |
| 低 | 仪器测试里的 30 文案残留 | 渲染断言会失败，属机械性改动 |

---

## 8. 验收清单（可执行）

- [ ] `ControlCommand(motor2 = Move.REVERSE)` 编码出的帧含 `,m2=R>`，字段顺序与 §1.2 一致。
- [ ] 解析不带 `m1`/`m2` 的 STA 不报错，两个方向字段为 `null`。
- [ ] 解析 `m1=F,m2=R` 得到两个枚举；解析 `m1=X` 判为 `Malformed`。
- [ ] `ControlCommand` 拒绝 `servoDegrees = -16 / +16`，接受 `-15 / +15`。
- [ ] 操控台两个电机的「前进/停止/后退」互不影响：点 M2 后退时 M1 保持原方向。
- [ ] 安全停止发出的帧同时含 `move=S` 与 `m2=S`。
- [ ] 舵机滑块两端为 ±15°，`steps = 29`，拖动一格变化 1°。
- [ ] 舵机预设按钮文案为 `左转 -15°` / `右转 +15°`，且选中态高亮正确（覆盖 L249）。
- [ ] 无障碍播报为"范围负 15 度到正 15 度"（覆盖 L326）。
- [ ] 关页面/切后台/断网后，安卓端保活停止使固件在 1 s 内两路都停（固件串口可确认 `m1=S,m2=S`）。
- [ ] 实板确认舵机物理行程：`-15° → 1750 µs`、`+15° → 1250 µs`、`0° → 1500 µs`。
- [ ] 四格兼容矩阵各跑一遍，结论与第 4 节一致。
- [ ] `./gradlew test` 与 `./gradlew connectedAndroidTest` 全绿；`lint` 无新增告警。

---

## 9. 与固件改动的一一对应

| 固件改动（**均已实现**） | 安卓对应改动 |
| --- | --- |
| `BfRemoteCommand` 增加 `m2`，缺省 `STOP` | `ControlCommand` / `ControlInput` 增加 `motor2`，默认 `Move.STOP` |
| `ascii_protocol.c` 解析可选 `m2=F/R/S` | `encodeControl` 追加 `m2=`；`parseStatus` 解析可选 `m1`/`m2` |
| `Protocol_EncodeStatus` 追加 `m1=` / `m2=` | `ProtocolFrame.Status` 增加两个可空方向字段 |
| `move=R` 不再返回 `E_STEP_REVERSE_UNSUPPORTED` | 反向默认放开，反向按钮可用 |
| `Motor_ApplyFailsafe` 两路 coast | 安全停止必须带 `m2=STOP` |
| 舵机无换相节拍；**占空比改为挡位制（95% / 60%）** | `step_speed` 还原为**挡位选择器**（`100`=满速、`60`=低速）；可暴露"低速挡"开关，但**不要**做成连续调速 |
| `CFG_SERVO_SAFE_*_DEG` = ±15 | `SERVO_RANGE = -15..15`，UI 预设 / 滑块 / 文案 / 无障碍同步 |
| `http_ui.c` 的 `SM` = 15；网页左右映射已修正 | —（网页端，不属安卓） |
| TIM2 载波 2 s 慢周期 | —（固件内部，对安卓透明，只需同步文案） |

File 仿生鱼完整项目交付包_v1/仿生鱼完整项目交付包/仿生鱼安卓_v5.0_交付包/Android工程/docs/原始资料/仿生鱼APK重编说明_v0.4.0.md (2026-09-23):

# 仿生鱼 Android 控制器 —— APK 重编说明（目标版本 0.4.0）

> **文档生成时间**：2026-09-11
> **目标**：从现有源码重新构建一个**可安装、能通过 V1 握手**的 APK，版本号 **0.4.0 / versionCode 6**
> **本文档面向执行构建的 AI/开发者（Codex）**。请**先完整读完再动手**，尤其是 §4、§5、§9。

---

## 1. 一句话目标

源码里**已经包含了修复"握手永远失败"的那处改动**。你的任务是**不要再改逻辑**，只做版本号提升（已由我改好）→ 跑单测 → 出 APK → 记录哈希。

**这次构建不是为了改 bug，而是为了把已经在源码里的修复编译成 APK。**

---

## 2. 源码位置（绝对路径）

```
工程根目录：
C:\Users\CloudyRain\Desktop\待办\仿生鱼工程\仿生鱼完整项目交付包_v0.3.1\仿生鱼完整项目交付包\仿生鱼安卓AP直连_v0.3.0_2026-09-06\Android工程
```

关键文件：

| 路径 | 说明 |
| --- | --- |
| `settings.gradle.kts` | 工程名 `BionicFishController`，`include(":app")` |
| `build.gradle.kts` | AGP `8.13.2`、Kotlin `2.3.21`、Compose 编译器插件 `2.3.21` |
| `app/build.gradle.kts` | **版本号在这里**（见 §3） |
| `gradle/wrapper/gradle-wrapper.properties` | Gradle **8.13**，带 `distributionSha256Sum` 校验 |
| `app/src/main/java/com/bionicfish/controller/protocol/AsciiProtocol.kt` | **最关键的文件**，见 §4 |
| `app/src/main/java/com/bionicfish/controller/device/DefaultBionicFishRepository.kt` | 握手流程 + 我加的保活，见 §5 |
| `app/src/test/java/...` | JVM 单元测试 |

> ⚠️ 父目录 `仿生鱼安卓AP直连_v0.3.0_2026-09-06\` 下的 `仿生鱼控制器_v0.3.0_AP直连.apk` 是 **2026-09-06 的旧产物，已过时**，不要拿它当基准，也不要覆盖它（见 §10）。

---

## 3. 版本号（**我已经改好了，请勿再改**）

`app/build.gradle.kts` 第 16-17 行：

```kotlin
        versionCode = 6
        versionName = "0.4.0"
```

变更记录：`versionCode` `5 → 6`，`versionName` `"0.3.2" → "0.4.0"`。

其余构建参数（**不要改动**）：

```
namespace / applicationId : com.bionicfish.controller
compileSdk                : 36
buildToolsVersion        : 36.0.0
minSdk                   : 26
targetSdk                : 36
Java / Kotlin target     : 17
buildTypes.release       : isMinifyEnabled = false（无 signingConfig，见 §6）
```

同时我已同步更新 `Android工程\README.md` 第 3 行的版本描述为 `0.4.0 / versionCode 6`，保持源码自洽。

---

## 4. 【最重要】导致握手失败的 bug —— 已在源码中修复，**不要回退**

### 4.1 现象（旧 APK 的实际表现）

手机 App 报：

> TCP 已连接，但 STM32 未完成 ACK + STA 验证；握手超时：未在 2000 ms 内同时收到 ACK 与有效 STA

### 4.2 根因

固件的状态帧**硬编码**发送 `step_rpm=NA`、`step_est=NA`（`ascii_protocol.c` 里写死的字符串，不是数值）。旧版 `AsciiProtocol.kt` 的 `parseStatus()` 里：

```kotlin
// ❌ 旧版（错误）：NA 解析成 null 后命中第一个条件，整条 STA 被判 Malformed 丢弃
if (
    sequence == null || link == null || stepTarget == null || stepEstimate == null ||
    ...
) {
    return DecodeResult.Malformed(ProtocolParseError.INVALID_VALUE, raw)
}
```

于是**每一条 STA 都被丢弃** → 握手的 `statusSeen` 永远为 false → 只能等到 2000 ms 超时。而 ACK 解析正常，所以 App 能收到 ACK 却永远"未完成验证"——**症状与根因完全吻合**。

### 4.3 修复（**当前源码已是修复后的状态，请原样保留**）

```kotlin
// ✅ 现行（正确）：NA 是合法值，只有"既不是数字也不是 NA"才判 Malformed
if (
    sequence == null || link == null ||
    (stepTarget == null && fields["step_rpm"] != "NA") ||
    (stepEstimate == null && fields["step_est"] != "NA") ||
    stepActual === InvalidNumber || servo == null || roll === InvalidNumber ||
    pitch === InvalidNumber || yaw === InvalidNumber || faults == null
) {
    return DecodeResult.Malformed(ProtocolParseError.INVALID_VALUE, raw)
}
```

**请确认这两行 `!= "NA"` 的存在。如果它们在，就不要动 `parseStatus()`。**

该文件在 git 中的修复提交为 `9b97230`（2026-09-09，提交信息 "fix: stabilize TCP control and simplify fixed low-speed propulsion"），旧 APK 早于它。

### 4.4 `parseStatus` 的完整契约（供你判断，不要擅自"简化"）

| 字段 | 固件实际发送 | 解析要求 |
| --- | --- | --- |
| `seq` | 0..65535 | `toIntOrNull()` 且落在 `SEQUENCE_RANGE` |
| `link` | `"0"` / `"1"` | 映射为 Boolean，其他值 → Malformed |
| `step_rpm` | **`NA`** | `NA` → `null` **且必须被接受** |
| `step_est` | **`NA`** | 同上 |
| `step_actual` | **`NA`** | `nullableNumber("NA")` → `null` |
| `step_on` | `"0"` / `"1"` | `null`（旧固件）→ 由 `step_rpm > 0` 推断；非法值 → Malformed |
| `servo` | `-30..30` 整数 | 超范围 → Malformed |
| `roll`/`pitch`/`yaw` | 一位小数的数值（如 `1.2`、`-5.1`、`74.7`） | `toDoubleOrNull()` 且 `isFinite()` |
| `err` | 十进制非负整数（如 `0`、`160`、`163`） | `toLongOrNull()` 且 `>= 0` |

**`err` 非零完全正常，绝不能因为 `err != 0` 就拒绝 STA。** 见 §9.2。

---

## 5. 我在源码里做的一处**有意**改动 —— 不要当作"多余代码"删掉

`DefaultBionicFishRepository.kt`（`performV1Handshake` 附近）新增了**握手期间的链路保活**：

| 新增内容 | 作用 |
| --- | --- |
| 字段 `private var handshakeKeepaliveJob: Job? = null` | 保活任务句柄 |
| `startHandshakeKeepalive(command, ticket)` | 每 `HANDSHAKE_KEEPALIVE_PERIOD_MILLIS = 400 ms` 重发**同一条命令、同一个 seq** |
| `stopHandshakeKeepalive()` | 在 `finally` 里停止，覆盖 ACK 等待段与所有异常路径 |
| 常量 `HANDSHAKE_KEEPALIVE_PERIOD_MILLIS = 400L` | 位于文件末尾的 `private companion object` |

**为什么必须复用同一个 seq**：固件对"同 seq 同载荷"只刷新保活计时、**不推进 `last_sequence`**，所以状态帧的 `seq` 始终等于握手 `seq`，握手探针的同序号匹配不会被打断。**如果这里改成新 seq，握手将永远无法通过。** 保活帧也不注册 ACK 等待器（会与 `queueAndAwait` 的同序号等待器冲突并触发其内部 `check`）。

**为什么需要它**：固件在最后一条被接受的命令后 `CFG_LINK_TIMEOUT_MS = 1000 ms` 就会主动关闭 TCP，而 App 的握手窗口是 `handshakeTimeoutMillis = 2000 ms`，且 `startPeriodicControl()` 要等握手通过才启动 —— 握手期间只有一条命令在续命。这是真实的潜在竞态；400 ms 的续命让它不再可能发生。

**这个改动在正常路径上是无副作用的**：握手健康时 < 400 ms 就完成，`finally` 先取消任务，保活帧一帧都不会发出。

---

## 6. 构建环境要求

| 项 | 要求 | 备注 |
| --- | --- | --- |
| JDK | **17 或以上** | 本机可用的为 JDK 21（`D:\JAVA\jdk-21.0.9.10-hotspot`）。AGP 8.13.2 需要 JDK 17+ |
| Android SDK | **必须已安装**（本机原本没有） | 需要 `platforms;android-36` 与 `build-tools;36.0.0` |
| `ANDROID_HOME` / `ANDROID_SDK_ROOT` | 指向 SDK 根目录 | 或写 `local.properties`：`sdk.dir=...` |
| 网络 | **首次构建需要联网** | Gradle 8.13 发行包 + AGP/Kotlin/Compose 依赖（数百 MB） |
| Gradle | 用仓库自带 wrapper（8.13） | `gradlew.bat` 已存在，**不要**改成别的版本 |

> ⚠️ **本机（生成此文档的机器）没有 Android SDK，也没有 `~/.gradle/caches`，因此我无法编译验证。** 构建必须在有 SDK 的机器/环境上完成。

---

## 7. 构建步骤

### 7.1 设置 SDK 路径

在 `Android工程\` 下创建 `local.properties`：

```properties
sdk.dir=C\:\\path\\to\\Android\\Sdk
```

（或设置环境变量 `ANDROID_HOME`。）

### 7.2 跑单元测试（**必须先跑，它是这次修复的回归证据**）

```bat
cd /d "C:\Users\CloudyRain\Desktop\待办\仿生鱼工程\仿生鱼完整项目交付包_v0.3.1\仿生鱼完整项目交付包\仿生鱼安卓AP直连_v0.3.0_2026-09-06\Android工程"
gradlew.bat :app:testDebugUnitTest
```

**期望：全部通过。** 其中与本次修复直接相关的用例是：

- `DefaultBionicFishRepositoryTest` → `mock scan handshake control telemetry and safe stop share one protocol path`
- `DefaultBionicFishRepositoryTest` → `handshake still requires status in addition to acknowledgement`（`ACK_ONLY` 模式，`handshakeTimeoutMillis = 100L`，**必须仍然失败并报"握手超时"** —— 这是"缺 STA 不能通过"的负向断言，不是 bug）
- `AsciiProtocolTest`（若存在）中针对 `step_rpm=NA` 的解析用例

**如果出现失败，先判断它是不是上述"负向断言"，不要为了让测试变绿而改协议解析逻辑。**

### 7.3 出 APK

```bat
gradlew.bat :app:assembleDebug
```

**请用 `assembleDebug`，不要用 `assembleRelease`。** 原因见下。

### 7.4 ⚠️ 签名陷阱（很容易踩）

`app/build.gradle.kts` 的 `buildTypes.release` **没有配置 `signingConfig`**。因此：

- `assembleRelease` 产出的是**未签名 APK，无法安装**（除非你另行配置签名）。
- `assembleDebug` 由 Gradle 用自动生成的 debug keystore 签名，**可以直接安装**。

历史交付也是走 debug 产物（`artifacts\BionicFishController-v0.3.0-debug.apk`）。

> 如果确实需要 release 签名版：请新建 keystore 并在 `app/build.gradle.kts` 中补 `signingConfigs`，**但那属于新增变更，需要单独说明**，不要悄悄加进去。

### 7.5 产物位置

```
app\build\outputs\apk\debug\app-debug.apk
```

请把它**复制/重命名**为交付用名字，建议：

```
C:\Users\CloudyRain\Desktop\仿生鱼控制器_v0.4.0_AP直连.apk
```

**不要覆盖**父目录里 2026-09-06 的 `仿生鱼控制器_v0.3.0_AP直连.apk`（保留作为历史对照）。

---

## 8. 构建后必须记录的信息

请在构建完成后**填写并回报**：

| 项 | 值 |
| --- | --- |
| 实际 `versionName` / `versionCode` | （应为 `0.4.0` / `6`） |
| APK 文件大小 | ______ 字节 |
| APK SHA-256 | ______ |
| 单元测试结果 | ______ 通过 / ______ 失败 |
| 构建用的 JDK 版本 | ______ |
| 构建用的 AGP / Gradle 版本 | `8.13.2` / `8.13` |
| 构建时间 | ______ |

核对版本号的方法（无需额外工具）：

```bat
powershell -c "Add-Type -AssemblyName System.IO.Compression.FileSystem; $z=[System.IO.Compression.ZipFile]::OpenRead('app\build\outputs\apk\debug\app-debug.apk'); $e=$z.Entries | ? {$_.Name -eq 'AndroidManifest.xml'}; 'manifest entries:'; $z.Entries.Count; $z.Dispose()"
```

或安装后用 `adb shell dumpsys package com.bionicfish.controller | findstr versionName`。

---

## 9. 现场验收：装上新 APK 后应该看到什么

### 9.1 成功判据

1. 手机加入热点 `BionicFish-AP`（密码 `12345678`），选"保持连接"。
2. App → **设备**页 → 点「AP 直连 / 连接」。
3. **应在约 1 秒内显示已连接**，App 日志出现：
   ```
   TX      <CMD,seq=1,move=S,turn=C,step_speed=60,servo=0>
   RX      Acknowledgement(sequence=1, duplicate=false)
   RX      Status(sequence=1, linkAlive=true, stepTargetRpm=null, stepEstimatedRpm=null,
                  stepActualRpm=null, servoDegrees=0, rollDegrees=…, pitchDegrees=…,
                  yawDegrees=…, faultBits=…)
   SYSTEM  V1 兼容握手通过：安全停止 ACK + STA
   ```
   **关键：`stepTargetRpm` 应为 `null`**（因为固件发的是 `step_rpm=NA`）。
   旧 APK 在此处会直接卡到 `握手超时` 并显示 `stepTargetRpm=0`。

4. 进入控制页，逐项验证：停止、前进（固定低速）、舵机 ±30°、姿态角实时变化。

> 我之前用 PC 直连固件实测过同样的握手，固件侧的行为是确定的：
> ```
> → <CMD,seq=1,move=S,turn=C,step_speed=60,servo=0>
> ← <ACK,seq=1,result=OK>
> ← <STA,seq=1,link=1,step_rpm=NA,step_est=NA,step_actual=NA,step_on=0,servo=0,roll=1.2,pitch=-5.1,yaw=74.7,err=160>
> ```
> 也就是说 **ACK 与同序号、`link=1` 的 STA 都会在毫秒级返回**。

### 9.2 以下现象**都是正常的，不要当 bug 追**

| 现象 | 说明 |
| --- | --- |
| `faultBits` / `err` ≠ 0（常见 `160`、`163`） | `128`=OLED I²C 异常、`32`=串口发帧丢弃（**一旦置位会锁存到断电**）、`2`=ESP 收字节丢失、`1`=链路超时。**协议只要求 `err >= 0`，非零不影响握手。** |
| `step_rpm=NA`、`step_est=NA`、`step_actual=NA` | 固件**故意**这样发：本机无编码器，60/100 只作旧协议兼容字段，不声明真实转速 |
| 重复发送同一帧时收到 `result=DUP` | 正确行为：固件对"同 seq 同载荷"判重并回 `DUP` |
| 同 seq 不同载荷收到 `<ERR,seq=N,code=E_SEQ_CONFLICT>` | 正确行为 |
| 姿态角长时间几乎不变 | 静止台面上 roll/pitch 恒定、yaw 只以 0.1° 步进缓慢变化，属正常 |
| 舵机指令后约 1 秒电机自动停 | 固件 `CFG_LINK_TIMEOUT_MS = 1000 ms` 失联保护；App 需周期保活 |

### 9.3 另一条独立验证路径（不依赖 APK）

固件当前工作在 **AP+STA 双模**，若手机/PC 与 ESP 处于同一外部网络（本项目实测为 `CTGU-T-Web`，ESP 地址 `192.168.3.40`），可直接从 PC 直连：

```powershell
$c = New-Object System.Net.Sockets.TcpClient
$c.Connect("192.168.3.40", 9000)
$fr = "<CMD,seq=1,move=S,turn=C,step_speed=60,servo=0>`n"
$b = [Text.Encoding]::ASCII.GetBytes($fr)
$c.GetStream().Write($b,0,$b.Length); $c.GetStream().Flush()
Start-Sleep -Milliseconds 800
$rb = New-Object byte[] 512; $n = $c.GetStream().Read($rb,0,512)
[Text.Encoding]::ASCII.GetString($rb,0,$n)
$c.Close()
```

**这条路径已经实测通过**，可作为"固件没问题、问题在 App"的对照。

---

## 10. 明确**不要**做的事

1. **不要**修改 `AsciiProtocol.kt` 的 `parseStatus()` / `parseAcknowledgement()` 逻辑（§4 的两行 `!= "NA"` 必须在）。
2. **不要**删除 §5 的握手保活代码，也不要把它的 seq 改成新号。
3. **不要**改 `CFG`/协议语义、帧格式、字段名 —— 固件侧已冻结，改任何一侧都会破坏兼容。
4. **不要**动 `gradle-wrapper.properties`、AGP/Kotlin/Compose 版本、`compileSdk`/`targetSdk`/`minSdk`。
5. **不要**为 release 添加签名配置（除非明确要求并单独说明）。
6. **不要**覆盖或删除父目录里 2026-09-06 的旧 APK。
7. **不要**把 `build/`、`.gradle/`、`local.properties` 等产物提交进版本库。

---

## 11. 故障排查

| 症状 | 处理 |
| --- | --- |
| `SDK location not found` | 设 `ANDROID_HOME` 或写 `local.properties` 的 `sdk.dir` |
| `Unsupported class file major version` / JDK 报错 | 换 JDK 17 或 21，并确认 `JAVA_HOME` 指向它 |
| 首次构建卡在下载 | 需要联网；确认能访问 `dl.google.com` 与 `repo.maven.apache.org` |
| `assembleRelease` 出的包装不上 | 见 §7.4，改用 `assembleDebug` |
| 单测失败于 `握手超时` | 检查是不是 §7.2 说的那条**负向断言**；若是其他用例失败，先看 §4 |
| 装上新 APK 仍握手失败 | 先把 App 的 **RX 日志**导出来比对 §9.1：若能看到 `Status(...)` 行即说明解析已修好，问题在别处 |

**导出 App 日志的方法**：底部导航 → **遥测**（心跳图标）页 → 滚到最底部 → 「本地通信日志」卡片 → 「**导出日志**」。会调起系统"保存到…"对话框，文件名 `bionic-fish-log-<时间戳>.txt`，内容是 TSV（`timestamp_epoch_ms` / `direction` / `message`，direction 为 `RX`/`TX`/`SYSTEM`）。
⚠️ 日志**只存在内存里**（上限 500 条），App 进程被杀就没了，**必须在握手尝试之后、App 还活着时立刻导出**。

---

## 12. 背景：这套系统是什么（便于判断改动是否合理）

```
手机 App ──TCP:9000──> ESP-01S (AT 固件, AP+STA) ──UART2 115200──> STM32F103C8T6
                                                                    ├─ TB6612 双桥 → 两相步进
                                                                    ├─ TIM3 50Hz → IP65 舵机
                                                                    ├─ 软件 I²C → JY901S 姿态
                                                                    └─ 软件 I²C → SSD1306 OLED
```

- **所有控制逻辑、失效保护、协议解析都在 STM32 上**；手机只是遥控界面。
- 帧格式：`<TYPE,key=value,...>\n`，TYPE ∈ `CMD` / `ACK` / `ERR` / `STA`。
- 握手流程：App 发一条**安全停止** `CMD`（`move=S,turn=C,step_speed=60,servo=0`）→ 要求在同序号 `ACK` 与 `link=1` 的 `STA` **都在窗口内到达**才算通过。
- 固件失联策略：最后一条被接受的命令后 **1000 ms** 无新命令 → 停步进、舵机回中、清序号窗口、关闭该 TCP 连接。
- ESP 固件版本（实测）：`AT version:1.7.4.0` / `SDK 3.0.5-dev`，**8Mbit(512KB+512KB)** ⇒ 属 NONOS AT 1.7.4 Nano 配置，**不要重刷 ESP**。

---

## 13. 交付清单（构建完成后应产出）

- [ ] `仿生鱼控制器_v0.4.0_AP直连.apk`（debug 签名，可安装）
- [ ] 单元测试全部通过的输出记录
- [ ] APK 的 SHA-256 与字节数（填入 §8 表格）
- [ ] 装机后 §9.1 的握手成功日志（App 导出的 `bionic-fish-log-*.txt`）

---

## 14. 一句话总结给执行者

> **只提升版本号（已改好）、跑单测、`assembleDebug` 出包。**
> **不要碰 `AsciiProtocol.kt` 的 `NA` 判断和握手保活 —— 那正是本次构建要交付的修复。**

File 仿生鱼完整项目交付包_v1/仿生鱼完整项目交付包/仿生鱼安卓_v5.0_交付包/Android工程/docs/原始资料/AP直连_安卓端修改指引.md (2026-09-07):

# AP 直连控制 —— 安卓上位机修改指引（给 GPT 的改动任务书）

> 目标：让「手机直连仿生鱼自身热点（ESP-01S AP）」成为一等公民的连接方式，
> 而不是只能"手机与设备在同一局域网（路由器）下手动填 IP"。
> 本文基于 2026-09-06 实测联调事实编写，供 GPT 定位并修改本安卓工程。

---

## 0. 结论先行（GPT 请先读这一节）

当前端到端链路是**「手机 = TCP 客户端 → 192.168.4.1:9000」**，协议是 **TCP 字节流承载 V1 ASCII 帧**。
在 AP 直连下：

- **不要**依赖"扫描发现设备"——当前 STM32/ESP 侧**没有 UDP 发现应答服务**，`UdpDiscoveryScanner`
  扫描不到任何真实设备，只能返回"已保存端点"。
- **不要**改传输/编解码层——现有 `TcpTransport` + 帧重组已完全够用，AP 直连与"同局域网"
  在传输层**没有任何区别**，区别只在：①手机当前连的是哪个 Wi-Fi（ESP 热点）；②连接目标固定为
  ESP 热点网关 `192.168.4.1:9000`；③UI/流程把"直连热点"做成一步操作。
- **必须**处理安卓"连上无外网热点会被自动切走/提示无互联网"的问题，否则链路连上又断。

所以这次改动的实质 = **新增一个"AP 直连"连接模式/流程 + Wi-Fi 前置处理 + 固定端点预置**，
不是重写网络栈。

---

## 1. 联调确定的硬件/固件事实（改动的前提）
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

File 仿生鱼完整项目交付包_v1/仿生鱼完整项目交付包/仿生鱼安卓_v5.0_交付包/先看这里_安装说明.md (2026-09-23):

# 安装这个 APK：BionicFish-v0.5.0.apk

版本 0.5.0 / code7，应用名“仿生鱼控制台”，大小 20,270,434 字节。桌面同名 APK 与交付包根目录 APK 完全相同，只需安装一次。

1. 将 `BionicFish-v0.5.0.apk` 作为原文件传到手机，完整保存后打开。文件后缀必须为 `.apk`，不是 `.zip`、`.apk.1`、`.bin` 或下载未完成的文件。
2. 安装 APK，不要打开 Android工程文件夹来找安装程序；项目 ZIP 仅用于保存源码和资料。
3. 安装后先用“设置 → 模拟设备”检查两路按钮，再连接真实鱼端热点。手机中的安装来源许可由你按系统提示确认，本次未更改手机安全设置。
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

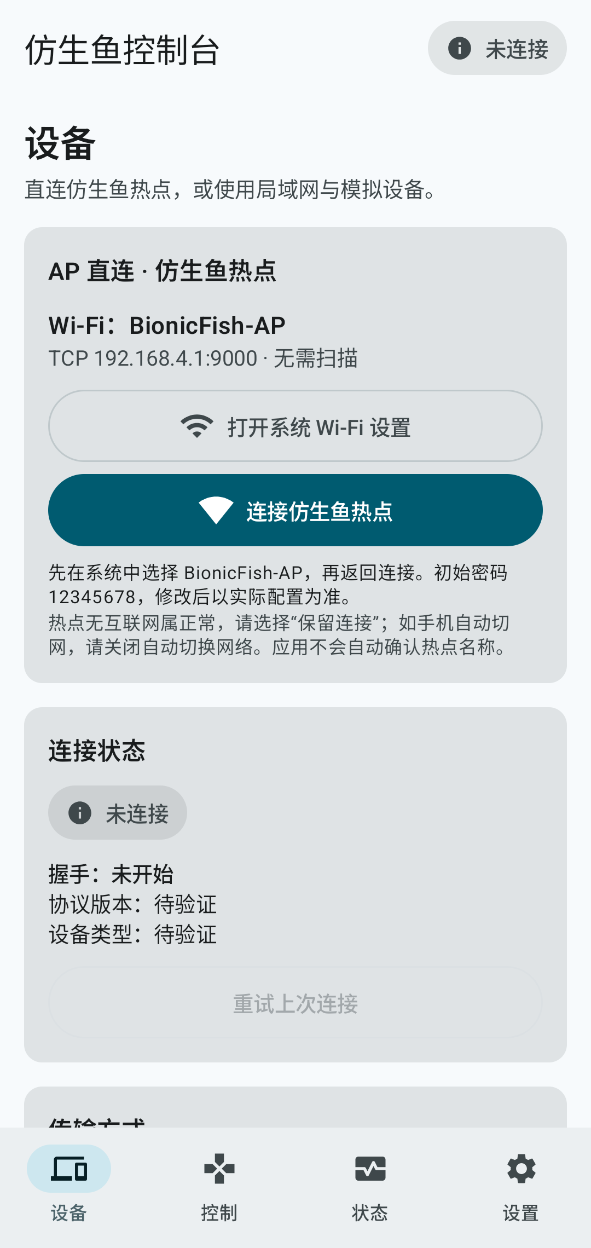
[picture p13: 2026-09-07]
仿生鱼完整项目交付包_v1/仿生鱼完整项目交付包/仿生鱼安卓_v5.0_交付包/Android工程/artifacts/renders/ap-direct-device-page.png

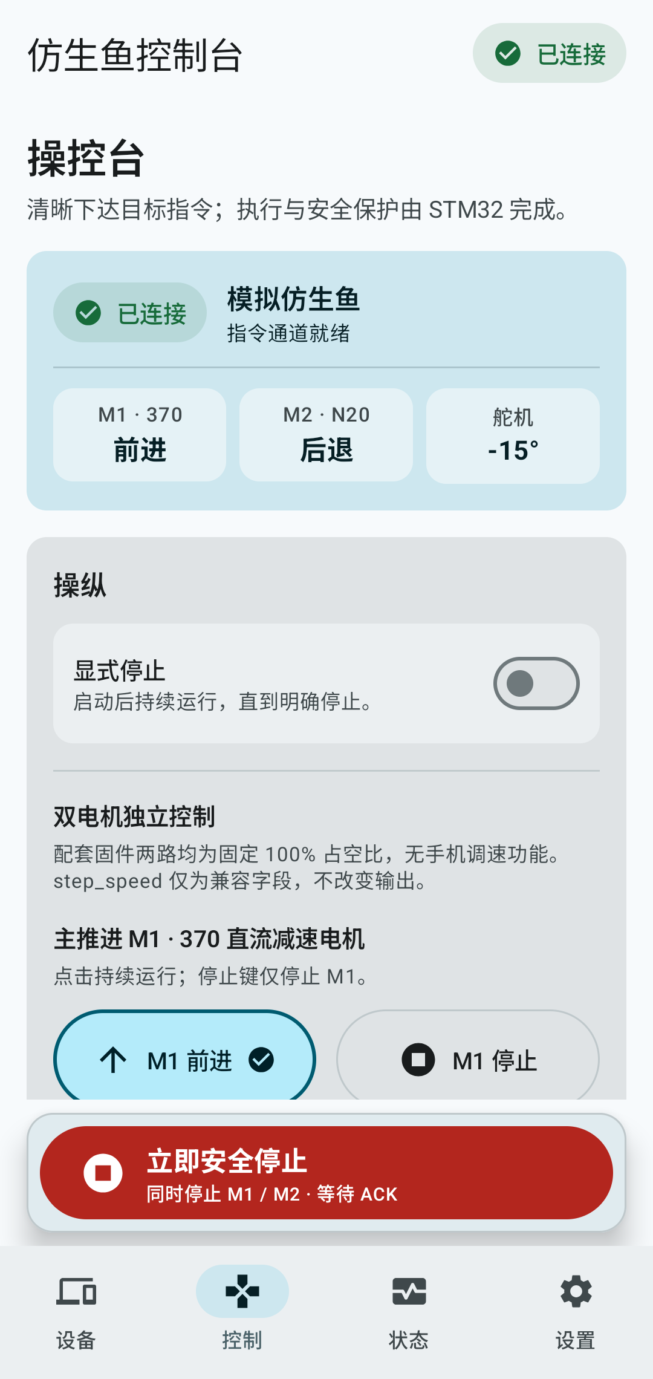
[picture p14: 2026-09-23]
仿生鱼完整项目交付包_v1/仿生鱼完整项目交付包/仿生鱼安卓_v5.0_交付包/Android工程/artifacts/renders/control-screen-light.png

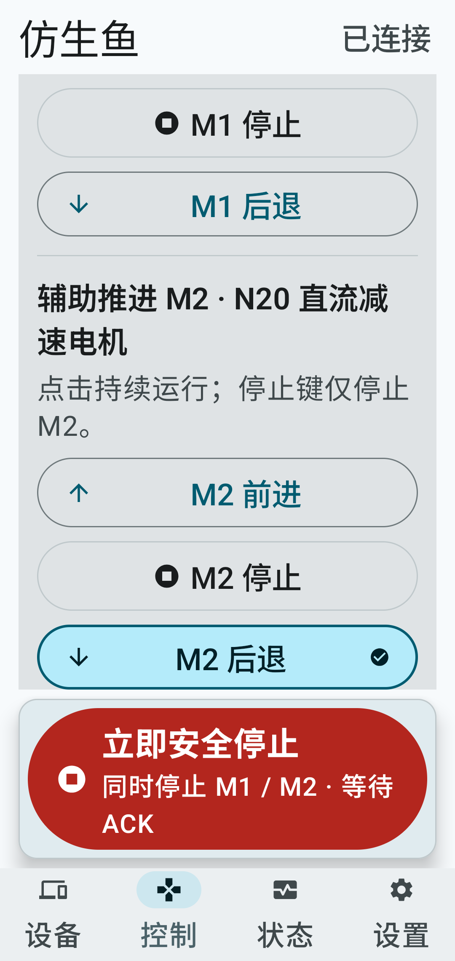
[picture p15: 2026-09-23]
仿生鱼完整项目交付包_v1/仿生鱼完整项目交付包/仿生鱼安卓_v5.0_交付包/Android工程/artifacts/renders/control-screen-200-percent-text.png

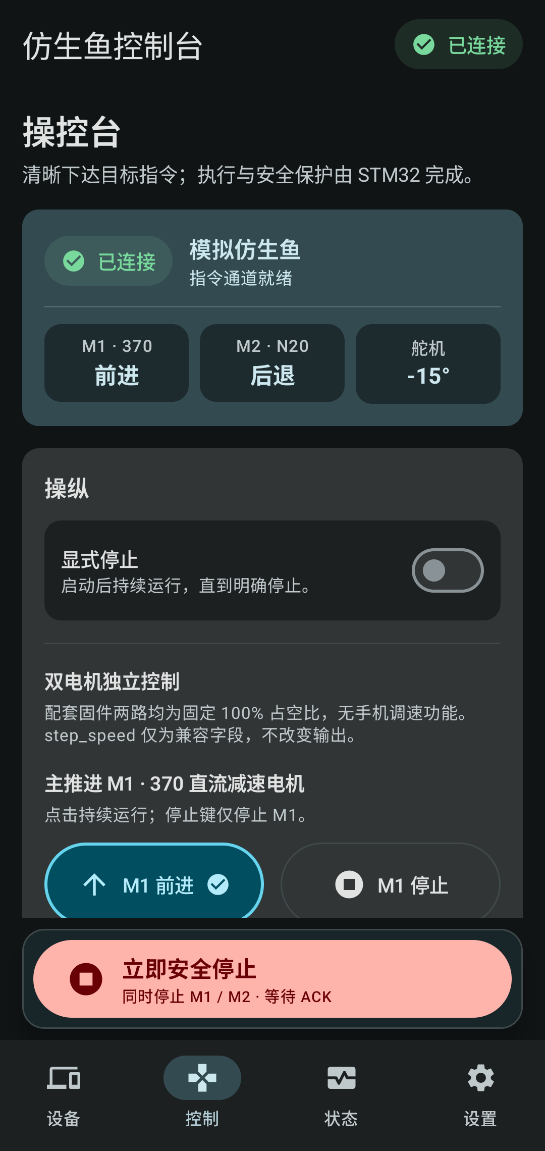
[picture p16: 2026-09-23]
仿生鱼完整项目交付包_v1/仿生鱼完整项目交付包/仿生鱼安卓_v5.0_交付包/Android工程/artifacts/renders/control-screen-dark.png

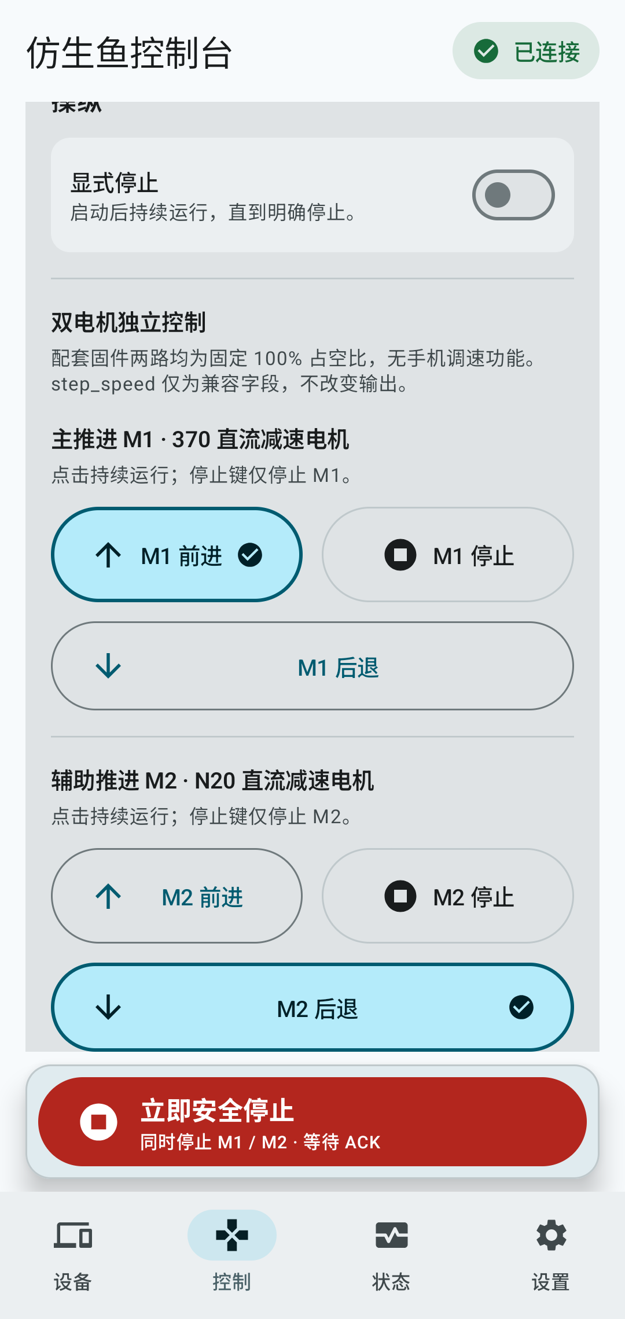
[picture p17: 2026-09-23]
仿生鱼完整项目交付包_v1/仿生鱼完整项目交付包/仿生鱼安卓_v5.0_交付包/Android工程/artifacts/renders/control-screen-dual-motor.png

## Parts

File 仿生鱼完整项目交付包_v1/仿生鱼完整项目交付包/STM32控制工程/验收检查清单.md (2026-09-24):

# 当前交付验收清单

当前范围：STM32 + ESP-01S AT/TCP + Android；**TB6612 驱动两路直流减速电机**（M1 = 370 主推进、M2 = N20 12V 版唧筒），各自独立启停与换向；TIM2 **2 s 慢周期载波**，满速挡 **95%** / 低速挡 **60%**；舵机安全行程 **±15°**；步进推进方案已作废。M2 唧筒链路 V1.0.0 起已实装。按键不启用（板上调试键为编译开关，默认关），OLED 保留单页布局，HarmonyOS 暂停。

## 软件验证

**本轮结果：host 侧 16/16 通过（含编译期门禁）。Arm 交叉构建已重做，产物见下。**

| 检查 | 判据 |
| --- | --- |
| C 宿主回归 | 16 个测试（可执行 + 编译期门禁）全部通过（本机 GCC 15.2 需 `-Wno-error=format-truncation`，见开发日志 6-3；未改 CMakeLists） |
| 两路直流电机 | 同一命令可同时下达 M1 推进方向与 M2 唧筒动作（`move=` 与 `m2=`），两路互不覆盖；两路共用同一挡位（满速 95% / 低速 60%）；无换相节拍，方向一经下达即保持 |
| PWM 提交时序 | 写入 CCR 后立即发 UG 事件强制提交，**不等待 2 s 自然更新**；重复设置同一值不产生多余动作；换向立即生效 |
| 停止与禁用 | STOP、失联、UART 丢失及发送失败使**两路同时 coast**；任一路被显式禁用时只有该路 coast，另一路不受影响 |
| 协议与链路 | 严格分帧、同序号幂等、逐命令AT响应、实际连接ID、接收损坏恢复、发送结果核查、旧会话隔离 |
| 舵机 | 限幅 ±15°；±16° 及以上返回 `E_RANGE`；网页左/右键与固件方向一致（不双重取反） |
| 网页界面 | 电机1/电机2 各有启停反转三键 + 一个 60% 低速挡开关；页面字节数在 `HTTP_RESPONSE_BYTES` 编译期门禁内 |
| 姿态与屏幕 | 错误/过期姿态不可用；OLED缺失不阻止握手，恢复后继续原单页信息显示 |
| Arm 构建 | 真实HAL/CMSIS及业务源码在Werror下交叉构建；产物见 `build-fw-v05/build-info.json` |
| 烧录脚本 | 6项模拟调用检查通过：连接模式、频率、BIN/ELF地址、空格路径和失败退出；记录见build-firmware/flash-wrapper-validation.json，未实际烧录 |
| Android 构建 | testDebugUnitTest lintDebug assembleDebug assembleDebugAndroidTest 成功；支持RPM为NA及step_on状态 |
| MuMu 测试 | 完整AndroidJUnitRunner通过；前进/停止、舵机、状态解析、TCP软件闭环和控制页操作验证 |

### 本轮 Arm 构建产物（`build-fw-http/`）

| 产物 | 字节数 | SHA-256 |
| --- | ---: | --- |
| `bionic_fish.bin` | 34,272 | `2559592197244234f67009fd26682a8785665dbe6f5fa6f692f3113653029e4a` |

占用：Flash **52.29%**（34,272 / 65,536 B）、RAM **79.92%**（16,368 / 20,480 B）。烧录前必须以本次产物为准，旧哈希已失效。

> 本版在 v0.5 基础上依次修复两处缺陷：① `CFG_ESP_WIFI_MODE` 回归（`3U` → `2U`）② `HTTP_RAW_BYTES` 小于 `HTTP_RESPONSE_BYTES` 导致 HTTP 响应静默发不出去。详见 `开发日志与修改清单.md` 附录 H 与附录 I。更早的 `build-fw-v05/`（`517de91e…`）与 `build-fw-fix/`（`333e4a52…`）已被取代。

host 侧本轮通过 **10/10**，Arm 交叉构建已重做。**实板烧录已验证**：下载 33.47 KB、`Download verified successfully`，独立回读 34,272 字节 SHA-256 与本地一致；USART3 观测 `server=1`、`error=OK`、`reset=0`、`uloss=40`（稳定）。

> ⚠️ **烧录注意**：若出现 `Error: failed to erase memory` / `failed to download Sector[0]`，先用「写 RAM `0x20000000`」做对照——RAM 成功而 flash 失败即可判定为 **MCU 内部 flash 故障**（与代码无关），需换芯片。`-e all` 报「Mass erase successfully achieved」不表示擦除真的生效。

Android当前版本0.3.2/code5，证据见其[验证记录](../仿生鱼安卓AP直连_v0.3.0_2026-09-06/Android工程/验证结果_2026-09-09.md)。使用官方ADB直接运行完整instrumentation APK，不将未完成的Gradle connected任务记为成功。

## 已有硬件信息

- 用户提供ESP AT1.7.4.0/SDK3.0.5-dev回包；修正后的当前UART为115273,8,1,0,0，匹配本工程115200/8N1/无流控。
- **两路直流减速电机**：M1 = 370 直流减速电机（带动鱼尾），M2 = N20 直流减速电机（**12V 版本**，驱动注射器式唧筒活塞实现沉浮）。两路各自两根引线，接在 TB6612 的 A01/A02 与 B01/B02 上；原 42 步进电机与线圈配对方案已作废。VM 约 12V，来自 45C、3S 航模锂电。
- **用户已确认 STBY 恒接高电平、VM = 12V**。因此本轮不再把"STBY 未使能"当作故障方向。
- 保留 TB6612，两路以 **满速挡 95% / 低速挡 60%** 运行。占空比是"开环调压"而不是限流或过流保护：TB6612 手册只有热关断与低压检测，**没有过流/短路保护规格**，堵转电流必须实测。

## 实板联调

| 操作 | 预期结果 | 证据状态 |
| --- | --- | --- |
| 烧录并启动STM32/ESP | USART3诊断server=1，出现BionicFish-AP，TCP9000可连接 | 待实板 |
| 安卓AP直连 | STOP收到同序号ACK及link=1 STA，页面进入已连接状态 | 待实板 |
| 两路分别驱动 | 单独点 M1 前进、再单独点 M2 唧筒推/拉，两路互不影响；观察唧筒活塞行程、方向、稳定性和温升 | 待实板 |
| **带载驱动（本轮重点）** | 满速挡下 M1 带动鱼尾能稳定启动并维持，**不再出现"有电压却带不动"**；用示波器/万用表确认 PWMA 每个 2 s 周期有一次完整低电平沿 | 待实板 |
| 低速挡切换 | 勾选"60% 低速挡"后两路明显降速，取消勾选恢复满速 | 待实板 |
| 停止、再次前进 | 停止时两桥 coast、`step_on=0`、`m1=S`、`m2=S`；再次给命令恢复 | 待实板 |
| 调整舵机 | 舵机响应且不打断两路电机方向；**网页左键确实左转、右键确实右转，实测行程 ±15°（左 1750 µs / 右 1250 µs）** | 待实板 |
| 退出App/断Wi-Fi/拔ESP | 失联停止，不恢复旧推进目标；重新连接先STOP握手 | 待实板 |
| 查看和恢复传感器/屏幕 | 姿态有效时正常显示；无效时NA/---；屏幕原布局能持续刷新 | 待实板 |

软件测试和模拟器不能证明实物电机、传感器及无线链路已正常工作。本轮还额外保留三项**必须实板确认**的风险： 2 s 慢周期 + 95% 占空比下 370 电机能否稳定带载； 堵转电流与 TB6612 温升； N20 唧筒的活塞行程限位（微动开关）接线与整机防水动密封。实板联调结果确认后，才能将整个工程正常使用标为完成。

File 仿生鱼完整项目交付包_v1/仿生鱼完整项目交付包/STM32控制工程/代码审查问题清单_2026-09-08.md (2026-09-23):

# STM32 控制工程代码审查问题清单

> 审查日期：2026-09-08　|　审查范围：`STM32控制工程/` 全部用户代码、`.ioc`、构建脚本与配套文档
> 审查方法：全量精读每个 `.c/.h`（约 3500 行，不含 HAL 生成库）＋ 4 路独立审查代理（控制层/协议层/底层/文档一致性）并行交叉检查 ＋ 全部高危结论逐条回读源码复核
> 严重度定义：**高**=会失败/失联/违反已承诺的安全语义，需尽快处理；**中**=健壮性/边界/集成缺口，建议修复；**低**=维护性/文档口径

---

## 0. 总览

| 类别 | 高 | 中 | 低 |
| --- | --- | --- | --- |
| A. 构建与工程结构 | 2 | 1 | 1 |
| B. 通信 / 协议 / 链路 | 2 | 3 | 1 |
| C. 控制与应用层 | 1 | 2 | 1 |
| D. 驱动与底层 | 0 | 3 | 3 |
| E. 文档一致性 | 1 | 2 | 2 |
| **合计** | **6** | **11** | **8** |

另：第 F 节列出**复核后判定为“设计自洽、不是缺陷”**的排查点，防止将来有人误改。

---

## A. 构建与工程结构

### A-1【高】CMakeLists 固件目标漏编 `esp_link.c`，按 README 走 CMake 交叉编译必然链接失败
- 位置：`CMakeLists.txt:41-75`（`add_executable(bionic_fish.elf ...)` 源列表），对照 `app/Src/app.c:64/187/239/353` 大量调用 `EspLink_*`
- 事实：固件目标源列表含 bsp_board/bsp_time/bsp_uart，**唯独没有 `bsp/Src/esp_link.c`**；而 `EspLink_Init/Send/Poll/RxOverflow/Service` 等只在 esp_link.c 中定义。host-test 目标不引用 EspLink，所以默认 `ON` 的主机测试全绿，掩盖了固件目标的问题。
- 旁证：已交付 `build-firmware/bionic_fish.bin` 是用 `scripts/build_firmware_direct.sh` 构建的，**该脚本的 `REPO_SRCS` 里明确包含 `bsp/Src/esp_link.c`**——两条构建路径的源列表已漂移。
- 影响：任何人按 README §“STM32 交叉编译”执行 CMake 路径，链接阶段报 `undefined reference to EspLink_*`。
- 修复：在 CMakeLists 固件源列表补入 `bsp/Src/esp_link.c`。

### A-2【高】交付的 `stm32f1xx_hal_conf.h` 缺失 `assert_param` 定义，任何“原样编译 HAL”的路径都会编译失败
- 位置：`Core/Inc/stm32f1xx_hal_conf.h`（全文 0 处 `assert_param`）；HAL 库每个源文件无条件调用 `assert_param(...)`
- 事实：标准 CubeMX 生成的 hal_conf 末尾必有 `#ifdef USE_FULL_ASSERT ... #else #define assert_param(expr) ((void)0U) #endif`，本工程被精简掉了。直连脚本因此被迫用 `-include build-firmware/assert_param.h` 注入空定义（`scripts/build_firmware_direct.sh:16-21` 及注释），并已把 hack 产物留在 `build-firmware/assert_param.h`。
- 影响：CubeIDE/CMake 从零构建（CMake 固件目标没有该 -include）都会在编译 HAL 源时失败。已交付 bin 能出来只是因为走了带 hack 的直连脚本。
- 修复：把 `assert_param` 空定义补回 hal_conf（或在 CMakeLists 增加同样的强制 include 并写入脚本说明），并删掉两套构建对 hack 的不对称依赖。

### A-3【中】构建路径三套并存且相互漂移，已交付 bin 不可按文档复现
- 位置：`README.md`（“STM32 交叉编译”只写 CMake 通用路径）vs `scripts/README.md`（只讲 flash）vs `scripts/build_firmware_direct.sh`（从未被文档提及，却是产出 bin 的真实路径）
- 事实：直连脚本硬编码本机绝对路径：`/c/Users/CloudyRain/STM32Cube/Repository/STM32Cube_FW_F1_V1.8.7`、`D:/STM32CubeIDE_1.19.0/...`、Arm gcc 13.3.1（与 `build-firmware/bionic_fish.map` 头部记录一致）；且其使用的 CubeF1 是 **V1.8.7**，而 `bionic_fish.ioc` 记录 `ProjectManager.FirmwarePackage=STM32Cube FW_F1 V1.8.6`。
- 影响：换机器/换版本无法一键复现交付 bin；文档口径与实际构建源不一致。
- 修复：在 README/scripts README 明确 `build_firmware_direct.sh` 是“本交付 bin 的实际构建脚本”，写明需替换的路径常量；统一 CubeF1 小版本口径（V1.8.6 vs V1.8.7）。

### A-4【低】交付包版本/日期口径混乱（v0.3.1 / v0.3.0 / v0.2.0 并存）
- 位置：`交付说明.md:1-3`（“对应 GitHub Release **v0.3.0**（2026-09-07）”、“Android 构建版本 **0.2.0**（versionCode 2）”）vs 交付包目录名 `仿生鱼完整项目交付包_v0.3.1` vs 安卓子包目录 `仿生鱼安卓AP直连_v0.3.0_2026-09-06`
- 影响：对外口径混乱，验收对照困难。纯文档问题，建议统一为单一对外版本号。

---

## B. 通信 / 协议 / 链路层

### B-1【高】`通信协议.md` §5 承诺的“UART 级丢字节（环形缓冲满 / ORE）立即安全断链并回 E_RX_OVERFLOW”**从未在代码接线**
- 位置：`bsp/Inc/bsp_uart.h:18-20`、`bsp/Src/bsp_uart.c:110-137,144-157`、`app/Src/app.c:187-205`；对照 `通信协议.md:55,80-81,125-133`
- 事实：
  - `BSP_Uart_OnRxComplete` 重挂失败、`BSP_Uart_OnError`（ORE）、`RingBuffer_PushFromIsr` 满时都会置 `s_esp_rx.data_lost = true`，`overflow_count++`；
  - 但 `BSP_Uart_EspRxLost()` / `BSP_Uart_EspRxOverflowCount()` **定义了却没有任何调用方**（全工程 grep 仅定义处）；
  - `app.c:187` 只检查 `EspLink_RxOverflow()`——那是 esp_link **软件 phone 缓冲**（256B）的溢出，不是 UART 环形缓冲(256B)或硬件 ORE。
- 影响：主循环被软 I2C/OLED 忙等拖住时，UART 环满丢字节无痕；ORE 丢字节只置位无人消费。**残缺字节可能被拼成一条恰好语法合法、语义合法的 CMD 被接受执行**——这正是协议文档承诺要防的“半真半假命令”。`BF_FAULT_ESP_RX_LOST`（bit1）文档语义为“UART 溢出/ORE 丢字节”，实际只在软件缓冲溢出时置位，语义错位。
- 修复：在 `ServiceProtocol` 顶部把 `BSP_Uart_EspRxLost()` 与 `L.rx_overflow` 同等对待：排空残留 → `Protocol_Reset` → `Control_ForceDisconnect` → `Motor_ApplyFailsafe` →（按配置回中）→ 回 `E_RX_OVERFLOW` → `BSP_Uart_ClearEspRxLost()`。

### B-2【高】esp_link 的 `+IPD` 解码状态机可被异常帧长/截断**永久卡死**，溢出清除也救不回
- 位置：`bsp/Src/esp_link.c:130-153`（`RX_IPD_LEN` 中 `ipd_len` 无限累加；`RX_IPD_DATA` 无兜底）、`esp_link.c:199-202`（`ClearRxOverflow` 只清标志）、`app.c:194`
- 事实：`+IPD,<id>,<len>:` 的 len 是**无上限 uint32 累加**。若 ESP 报文被截断（客户端中途断开）、或 len 巨大、或 `':'` 始终不出现，状态机停在 `RX_IPD_DATA`/`RX_IPD_LEN`，把后续**所有真实帧字节当幻影帧载荷吞掉**。`rx_overflow` 触发后 app 清标志并复位协议/会话，但**没有把 `L.rx` 复位到 `RX_IDLE`**——吞字节继续，标志被再次置位，形成“每次 ServiceProtocol 都进溢出分支”的死循环式链路瘫痪（直到幻影 len 被真实流量凑满才偶然恢复）。
- 修复：① `ipd_len` 设合理上限（如 `4×CFG_PROTOCOL_PAYLOAD_MAX`），超限即复位；② `ClearRxOverflow` 顺带 `L.rx = RX_IDLE; L.ipd_len = 0; L.ipd_got = 0;` 并把 phone 缓冲内残留置为无效；③ 在 `RX_IPD_DATA` 加字节间隔超时看门狗，超时强制回 `RX_IDLE`。

### B-3【中】下行 CIPSEND 无握手、无重试，三次独立入队不原子 → 可撕裂帧、ESP 端悬挂
- 位置：`bsp/Src/esp_link.c:204-216`（`SendQueuedFrame` 三次调用 `RawCstr/BSP_Uart_SendEsp`，返回全部忽略）、`bsp/Src/bsp_uart.c:47-61`（队列满即丢）
- 事实：`AT+CIPSEND=0,<len>` 头、帧体、`\r\n` 分三次入同一 512B 串口 TX 队列，**中间若队列满，只有部分字节发出** → ESP 收到 CIPSEND 头却等不到足量载荷（等待/超时后 `SEND FAIL`），后续被发的下一条 `AT+CIPSEND` 会被当载荷吞掉，形成串行错乱链。代码也不等 ESP 的 `>` 提示、不解析 `SEND OK/ERROR/link is not valid`（非 `+IPD` 行全部只喂给 `OK` 判断）。
- 影响：主要出现在串口 TX 队列拥塞或 ESP 客户端断开瞬间；对即时 ACK/ERR 是**不可弥补的丢帧**。
- 修复：三个入队调用改为检查返回并整体失败即回滚/重试；或引入下行状态机（发头 → 等 `>` → 发体 → 等 `SEND OK`）；至少让 `slots` 满时的处理不撕裂串口序列。

### B-4【中】ACK/ERR 与周期 STA 同权排队、满即丢且无事件级重传
- 位置：`bsp/Src/bsp_uart.c:47-61`、`app/Src/app.c:62-87`（Broadcast）、`esp_link.c:33`（slots=4/冷却 150ms）
- 事实：`EspLink_Send` 满则返回 false，`Broadcast` 只置 `BF_FAULT_UART_TX_DROPPED`。ACK/ERR 是“一帧一个语义”的事件性应答（如 `E_STEPPER_HW_UNCONFIRMED`、`E_RANGE`），丢了上位机就可能**误判命令已被接受并继续下一步**；STA 丢了 200ms 后自然重发，二者不应同权。
- 修复：ACK/ERR 走更高优先级槽位（可挤掉队尾未发出的旧 STA），或满时保留最新事件帧并丢最旧。

### B-5【低】组帧/失联超时（250ms/1000ms）对主循环节拍敏感，缺乏硬调度保证
- 位置：`app/Src/app.c:165-220`（帧超时按主循环轮询字节时间戳判定）、`app.c:253-302`（`OledBringUp` 忙等最长约 8×100ms＋扫描探测，`I2cScanDebug` 约 112 次探测）
- 事实：初始化期间 ~1s 级忙等窗口内 ESP 持续来字节会灌满 256B UART 环（约 22ms 即满）——与 B-1 叠加是启动即丢帧的主要温床。运行期每条软 I2C 事务是 μs~ms 级忙等，但每轮只做一项 OLED 工作，理论上不会持续 >250ms 停摆（OledBringUp 只在启动），故运行期风险中等偏低，但**没有 IWDG/任务超时兜底**。
- 建议：初始化忙等期间暂停订阅/清空链路，结束进环前 `RingBuffer_Reset`；或在 README“运行边界”明确该启动窗口行为。

---

## C. 控制与应用层

### C-1【高】每个“内容相同、seq 前进”的重复命令都会把步进换相时钟拨回 now → 相位被提前截断、实际转速偏高且抖动
- 位置：`app/Src/app.c:130-131`（每个新命令都 `Motor_ApplyCommand`）→ `control/Src/motor_control.c:92`（`next_commutation_us = now_us`）
- 事实：只有同 seq 同载荷才走 DUP 分支（不重排时钟）；**seq+1 的同载荷刷新命令**（心跳/重发、舵机微调时连带）每次到达都会让 `Motor_Service` 在下一个主循环立刻多换一相，把“进行中相位”的驻留时间从最大一个周期压到几 ms。若上位机以 <1s（保活 1000ms 要求）周期刷新，则稳态换相速率 = 额定 + 刷新率×(每命令一相)，**实际转速高于指令值且不确定**。
- 影响：60/100 RPM 两档名义速度在真实链路下偏快/抖动；在未确认参数阶段不易察觉（门禁未开），一旦确认参数通电可能表现为转速超预期。
- 修复：`Motor_ApplyCommand` 改为“幂等不重排”：仅当 move/rpm 相对上次变化（或当前停转）时才重排 `next_commutation_us`；同目标重复命令只刷新保活，不动换相时钟。

### C-2【中】步进参数门禁缺少上限/溢出防护：配置错误会“静默停转”或给出错误转速，且无任何故障位
- 位置：`app/Inc/app_config.h:125-129`（只校验非 0）vs `control/Src/motor_control.c:31-35`（`denominator = rpm × comm` 无界 32 位乘法）
- 事实：`CFG_STEPPER_COMMUTATIONS_PER_OUTPUT_REV` 无上限检查：乘积溢出 → `denominator` 回绕成小值 → 错误的高换相频率；`denominator > 60e6` 时 `period_us` 截断为 0 → `StopStepper` **静默停转**——命令已被 ACK、`step_running` 却为 false，无 `BF_FAULT`。同期也没有“每输出转换相数 × 60/100 rpm 产生的最低驻留时间须大于代码开销”的编译期/启动期检查。
- 修复：为 comm 增加合理范围（如 4..20000）的 `#if` 校验；`StepPeriodUs` 结果做饱和与 0 判定并置 `BF_FAULT_CONFIGURATION`；在确认参数的门禁通过时打印/上报实际算出的周期。

### C-3【中】三个物理按键（KEY1/KEY2/KEY3）零消费、无去抖，.ioc 名称与真实配置矛盾
- 位置：`bsp/Src/bsp_board.c:142-161`（`BSP_ButtonPressed` 定义）— 全工程**无任何调用方**；`Core/Src/gpio.c:37-45`（普通 `GPIO_MODE_INPUT` + 上拉）；`bionic_fish.ioc`（KEY3 PA8 写 `GPIO_ModeDefaultEXTI`，名称暗示外部中断）；`app_config.h:35` `CFG_BUTTON_DEBOUNCE_MS` 无使用者
- 影响：若任一键本意是本地急停/安全功能，则当前固件该功能**完全失效**（安全只能靠链路）；即使只是预留，也是“物理硬件存在但软件死代码 + 配置名称误导”。README/交付说明均未声明按键用途。
- 修复：要么明确删除按键接口与 .ioc 的 EXTI 字样（改普通输入描述）；要么在 `App_Process` 接入按键功能（含按 `CFG_BUTTON_DEBOUNCE_MS` 去抖），并在文档写明每个键的动作。

### C-4【低】PC13 快闪/慢闪诊断语义（OLED 是否起来）只在代码里，文档/验收清单未写明
- 位置：`app/Src/app.c:377-381`（`s_oled_ok ? 500ms : 120ms`）
- 事实：代码用闪烁频率区分 OLED 初始化成败（快闪=没认到屏），README“首次上电”与 `验收检查清单.md` 都只让“观察 PC13”，未解释判别规则。
- 修复：README/验收清单补一句：“PC13 快闪（约 120ms）＝OLED 初始化失败；慢闪（约 500ms）＝正常”。

---

## D. 驱动与底层

### D-1【中】OLED 半途刷屏失败后的恢复链路偏脆弱；上电首次失败后**永不重试**（黑屏 + 只能靠快闪诊断）
- 位置：`drivers/Src/ssd1306.c:190-240`、`app/Src/app.c:253-278`（`OledBringUp`）、`oled_ui.c:61-71`
- 事实：复核结论——运行期单次失败后 `refresh_active=false → IsIdle=true`，下一轮 `OledUi_Update`（200ms 后且空闲）会整帧重画，**能自愈**，但整帧从页 0 重发、无断点续传；`i2c_error_active` 只在完整一帧成功后清除，期间 app 每轮置 `BF_FAULT_OLED_I2C`，故障位会随刷屏节奏闪烁。真正缺口在**上电路径**：`OledBringUp` 只在 `App_Init` 尝试（8 轮 × 每次失败等 100ms），之后永不再尝试；屏在复位窗口未就绪 = 整机工作期间黑屏，只能靠快闪诊断，无后台重试。
- 修复：把 OLED 重试并入运行期 Service（如每 1~2s 在 fault 置位且 idle 时重新 Probe/Init），而不是只在启动试一次。

### D-2【中】USART3 只配 TX 却按 TX_RX 初始化且无 RX 缓冲/错误恢复，调试口方向理解易错
- 位置：`bsp/Src/bsp_uart.c:99`（只对 huart2 开 `HAL_UART_Receive_IT`）、`bsp_uart.c:130-137`（`BSP_Uart_OnError` 只处理 huart2）、`Core/Src/usart.c:15`（`UART_MODE_TX_RX`）
- 事实：CH340N 回发（PB11）没有接收缓冲、没有重挂、没有消费；若有人往调试口发命令/回显，字节进不了固件，且 ORE 语义没有处理分支（HAL 层仍会清标志，不会锁死，但表现为“发了没反应”）。
- 修复：明确 `huart3` 为 `UART_MODE_TX`（或补 Receive_IT + 消费路径），并在文档写明“调试口仅输出”。

### D-3【中】JY61P 连续失败后旧姿态仍参与“合理性”比较 → 失效恢复后的首个有效样本可能被误杀
- 位置：`drivers/Src/jy61p.c:83-116`
- 事实：I2C 失败时保留旧数值仅置 `valid=false`（注释说明用意是“旧值不伪装实时”）；但下次成功读取后 `IsPlausible` 仍拿这个**很久以前的旧值**与候选值比较，鱼体若在断链期间大幅运动，新样本会被误判 SAMPLE_INVALID，失败计数继续累加（3 次又触发一次 BusRecover+Probe）。系统能自愈，但首次恢复会额外多失败几次、故障位抖动。
- 修复：合理性比较在 `!old_value->valid` 时直接放行即可（代码 34-35 行已有该分支，但 invalid 后旧数值没被清——建议 invalidate 时同时把姿态数值归零或保留 `last_update_ms` 判断新鲜度）。

### D-4【低】TIM2 coast 语义依赖“CCR 可安全大于 ARR（=100% 恒高）”的 F1 未文档化行为
- 位置：`bsp/Src/bsp_board.c:9-16`（`PercentToCompare` 上限 100 → `CCR=period=3600 > ARR=3599`）、`bsp_board.c:119-129`（Coast 置 CCR=100%）
- 事实：F103 比较器对 CCR>ARR 永不匹配 → 输出恒高，与 IN1=IN2=低共同构成 TB6612 coast。逻辑自洽且安全，但这是**依赖硬件行为的隐性约定**：若有人把 Coast 实现改成“PWM=0”，会从 coast 变成文档注释里明确警告过的非 coast 态（`bsp_board.c:80-82`）。建议加显式注释/`assert(CCR<=ARR+1)`，说明“coast 必须 IN=低+PWM=高”。

### D-5【低】软件 I²C 强依赖“外部 3.3V 上拉已接”与 5µs 半周期参数，总线被强拉死时恢复能力有限
- 位置：`drivers/Src/soft_i2c.c:201-221`、`Core/Src/gpio.c:31-35`、`app_config.h:58-64`
- 事实：OD 输出 + 无内部上拉；若上拉缺失/接错 5V，所有读采样浮空（代码无法自检，只能靠 `I2CSCAN` 启动打印间接判断——这个打印设计是对的，值得写进文档）；`BusRecover` 对“从机强拉低”只能 9 脉冲后超时放弃。文档已标“待实测”，此处仅建议把 `I2CSCAN` 输出补进 README 故障排查章节。

### D-6【低】`Ssd1306_Init` 内 `memset(display,0)` 之后地址/总线重设，若 `SoftI2c_Probe` 失败会留下 `i2c_failures++` 但 OledBringUp 换地址重试会重复计数——无功能影响，仅供诊断计数语义注明。

---

## E. 文档一致性（除 B-1/E 外跨交付包问题）

### E-1【高】ESP 桥接“双层交付”互相矛盾：固件是 AT/TCP 方案，配套文件夹却教人刷无 AT 的自定义透传桥
- 位置：`bsp/Src/esp_link.c:4-11,208,230-233`（发 `ATE0/CIPMUX=1/CIPSERVER=1,9000/AT+CIPSEND`、解析 `+IPD`，要求**出厂 AT 固件 + TCP**）vs `ESP01S_AP_UDP_Bridge/README.md`（“STM32 固件**不需要任何改动**”）与 `ESP01S_AP_UDP_Bridge.ino`/`ESP01S_TCP_Transparent_Bridge.ino`（无 AT 的 UDP/TCP 透明字节管道，UART 是干净管道，`+IPD`/CIPSEND 不存在）
- 事实：两种形态**互斥**。若按交付包内的 UDP 桥 README 烧了自定义固件，esp_link.c 发的 `AT+...` 会变成发给手机的普通 UDP 数据、上行的 `+IPD` 解析永远等不到 → 控制链路整体失效。而若保持出厂 AT 固件，则“STM32 不需要任何改动”的说法才是对的（指对 esp_link 的 AT 驱动而言）。Android 侧文档允许 TCP/UDP/Mock 并存并标“待确认”，进一步放大歧义。
- 修复：在 `ESP01S_AP_UDP_Bridge/README.md` 顶部加显著告警：**本桥仅当固件未采用 esp_link.c 的 AT 驱动时可用；当前交付固件 = AT + TCP（CIPSERVER=1,9000），请保持 ESP 出厂 AT 固件，勿刷本目录固件**；或在交付口径中收敛出唯一放行形态。

### E-2【中】板级“舵机 2（PA7）/ USART1（PA9/PA10）”在原始资料存在、在交付口径中无解释
- 位置：`原始资料/STM32拓展板_2026-08-26_引脚分配.md` 总表（舵机 2→PA7、USART1→PA9/PA10）vs `Core/Inc/main.h`/`bionic_fish.ioc`（无 PA7/PA9/PA10 任何业务信号）vs `硬件引脚与驱动说明.md` 引脚表（无这两行）
- 事实：实板资料上有第二路舵机与预留串口，但交付文档没写明“本交付不用/悬空”，用户拿到板可能误判功能缺失，也可能自行往 PA7 接舵机（固件无 PWM 输出 → 舵机不动）。
- 修复：在 `硬件引脚与驱动说明.md`/README 加一行：“拓展板资料的 舵机2(PA7)、USART1(PA9/PA10) 不在本交付支持范围，引脚悬空；启用需重配 CubeMX 并实测。”

### E-3【中】`README.md` 顶部“已用 HAL 桩完成全量源码零诊断语法/链接检查”的验证物不在交付内
- 位置：`README.md` “主机侧协议检查”段末；目录内只有 `tests/host`（不含 HAL 桩）
- 事实：桩验证脚本/记录未随交付给出，读者无法复现该声称。与 A-2/A-3 一起构成“构建可信度”缺口。
- 修复：把桩工程或检查记录一并放进 `tests/`，或删除该声称。

### E-4【低】OLED `E:` 十六进制低 12 位与 STA `err=` 十进制未在验收清单说明
- 位置：`ui/Src/oled_ui.c:39,44`（`%03lX` + `&0xFFF`）vs `验收检查清单.md`（只讲十进制位图）
- 修复：清单补一句“屏上 err 为十六进制且截断低 12 位，与串口十进制不同”。

### E-5【低】`通信协议.md` 字段表说“帧载荷最大为 `CFG_PROTOCOL_PAYLOAD_MAX-1`（191 字节）”，实际解析器在 `length >= PAYLOAD_MAX-1` 时报 E_TOO_LONG（即 192 字节数组保留 1 字节 NUL，191 可存）——一致；但测试未覆盖该边界（见 F-4）。文档口径无需改，测试需补。

---

## F. 复核后判定为“设计自洽 / 非缺陷”的排查点（防止误改）

以下各项经我逐条重读确认**不是问题**，修改前请三思：

1. **时钟树**：HSE 8MHz ×9 → 72MHz；APB1=36MHz（F1 定时器×2=72MHz）。TIM2 PSC0/ARR3599=20kHz ✓；TIM3 PSC71/ARR19999=50Hz 且 **1 count=1µs**（CCR 即脉宽 us）✓；TIM4 PSC71/ARR65535=1MHz 时基，`BSP_Micros` 的双读护栏正确 ✓。静态 `#if` 校验（app_config.h:103-129）与实际值全部通过。
2. **步进换相数学**：`60e6/(rpm×comm)` 量纲正确（60 s/min × 1e6 µs/s），与 TIM2 20kHz 无关（相位驻留由 TIM4 微秒时基调度，属软件换相设计）✓；`(step_phase - 1U) & 0x03U` 在 phase=0 时经无符号提升回绕到 3，反向换相正确 ✓；四拍表顺序与 reverse 异或逻辑自洽 ✓。
3. **序号窗口**：`delta∈[1,0x7FFF]` 新帧、`0x8000` 歧义拒绝、`>0x8000` 旧帧；超时/溢出清 `sequence_valid` 允许重链 ✓（host 测试已覆盖回绕，`protocol_host_test.c:101-124` 通过）。
4. **SPSC 无锁环形缓冲**：ISR 单写 head、主循环单写 tail、2 的幂门禁、留一槽判满——正确。
5. **TIM2 CCR=100%（=ARR+1）→ 恒高 = coast 前提**：见 D-4，行为本身安全。
6. **复位初始安全态**：`gpio.c:13-18` 先写电平再配输出（AIN/BIN 低、LED 灭、I²C 释放），TIM3 启动前 CCR 已预置 1500（`tim.c:47`）→ 舵机无启动毛刺 ✓。
7. **NVIC/中断**：分组 4、USART2=1 / TIM4=2 / USART3=2 与 .ioc 一致；中断只做入队/重挂，无阻塞业务 ✓。
8. **`step_running=true` 时 PWM 0% 不动**（`CFG_STEPPER_WINDING_PWM_PERCENT=0` 门禁）：这是**设计**——参数未确认前拒绝励磁并置 `BF_FAULT_STEPPER_HW_UNCONFIRMED`，不是 bug（README 已明示）。
9. **`move=S` 仍要求 step_speed/servo/turn 合法且字段全齐**：协议表明确约定，属设计。
10. **STBY 无 STM32 控制脚**：代码注释与三份文档一致承认这是硬件失效保护缺口，等待实测——不是代码漏项，但**是上电前的真实硬件待办**（务必保证 STBY 被可靠拉高）。

---

## G. 建议处理顺序

1. **动硬件/通电前必办**：E-1（ESP 固件形态收敛——当前固件=AT+TCP，别刷 UDP 桥）＋ STBY 实测（F-10）＋ 步进参数确认（F-8 门禁才允许解除）。
2. **建议优先修（直接影响链路安全语义）**：B-1（数据丢失检测接线）、B-2（+IPD 卡死）、C-1（重复命令打乱换相）、B-4（ACK/ERR 优先级）。
3. **构建可信度**：A-1、A-2、A-3（CMake 漏源/assert_param/构建路径漂移）。
4. **健壮性**：B-3、C-2、C-3、D-1、D-2、D-3。
5. **文档**：A-4、C-4、D-5、E-2~E-5。

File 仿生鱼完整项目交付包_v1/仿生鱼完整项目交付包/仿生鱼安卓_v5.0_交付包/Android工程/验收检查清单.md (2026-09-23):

# v0.5.0 验收检查清单

范围：新 Android 工程和 APK；不改写 STM32/ESP，不以用户文档中的固件实测描述代替本机证据。

## 1. 本机交付证据

本版构建、lint、JVM/UI 测试执行数量与结果、APK 元数据、签名、SHA-256、截图均以 [v0.5.0 构建验证结果](artifacts/v0.5.0构建验证结果.md) 为准。下表“已实现/有测试”只表示代码和用例已落地，是否实际通过请查报告；不沿用 v0.4.0 历史统计。

| 项目 | 实现与检查依据 |
| --- | --- |
| 版本与工程隔离 | v0.5.0 / code7，原 v0.4.0 不覆盖；构建依赖冻结，debug 签名。 |
| 完整双路命令 | CMD 尾随 m2；M1/M2 独立 F/R/S，单路操作保留另一完整目标；协议/仓库测试。 |
| 双路安全停止 | 明确 move=S,m2=S；回中/保留角、后台、离页、断开、换设备与重连路径检查。 |
| 单路优先停止 | 只停一路，避免误作全局急停；不因普通控制节流吞掉停止。 |
| 舵角边界 | UI ±15、steps=29、命令拒绝±16；STA 独立接收±30兼容旧固件。 |
| 回传方向 | 可选m1/m2缺失为未知，非法/重复拒收；step_on仅M1，NA不填0。 |
| 握手 | 同seq ACK+link=1 STA，400ms同序号双停保活，超时/取消清理。 |
| 反向设置 | 新装true，旧false保持；设置同时约束两路，关闭前双停；持久化测试。 |
| AP直连 | 原Wi-Fi专用路由与独立配置保留，不扫描AP，不伪造蓝牙或RSSI。 |
| Mock与旧帧 | 双方向组合、m2缺省停止、粘拆包/非法帧、旧STA/NA/err等协议回放。 |
| UI | 两组控件、±15标签/选中态/语义、固定停止栏、过期状态与深浅主题。 |
| 隐私 | 本地日志主动导出，无默认上传；未增加未使用的危险权限。 |

## 2. 尚未完成的实机项目

- [ ] 三星 S24 安装/升级、版本 code7、签名兼容和文件后缀核对。
- [ ] 确认实际为 M1=370、M2=N20 的配套直流固件，核对供电、极性、负载、电流与固定占空比。
- [ ] 确认固件 ±15° 行程与网页端 ±15° 均已配套；本次仅 Android，不能保证全系统限角。
- [ ] 确认 AP 名称/密码/IP/端口、AT/+IPD桥接以及 STM32/ESP 实际固件版本。
- [ ] 移动数据开启、热点无互联网情况下连接稳定，先双停再逐路低风险台架动作。
- [ ] M1/M2分别前进/停止/反向，验证换向及一路停止不影响另一路；全局急停双停。
- [ ] 舵机中心与±15°物理行程；用户方案期望脉宽为0°=1500µs、-15°=1750µs、+15°=1250µs，本机未测。
- [ ] 手动断网/ESP断电/MCU重启/切后台/锁屏时真实失联停机和回中，记录停止帧不可达时的行为。
- [ ] 新旧APK×新旧固件四向矩阵实际跑握手→两路动作→停止；旧固件忽略m2/拒绝反向只作预期，不作已验收。
- [ ] S24 TalkBack、200%字体、横竖屏、暗色、系统减少动画与长时间连续操作。

## 3. 放行限制

模拟器、Mock、单元测试不能证明电机实际方向、舵角、供电或水中安全。先卸载危险负载并备妥立即断电，再做台架联调；无线停止不是硬件急停。旧APK ±30°按钮与新±15°固件不兼容，应安装新版。

AP参数已有用户资料来源但未本机复测；普通LAN/UDP发现与蓝牙UUID仍待确认。协议不加密且无设备身份认证，不可将握手通过解读为强身份认证。

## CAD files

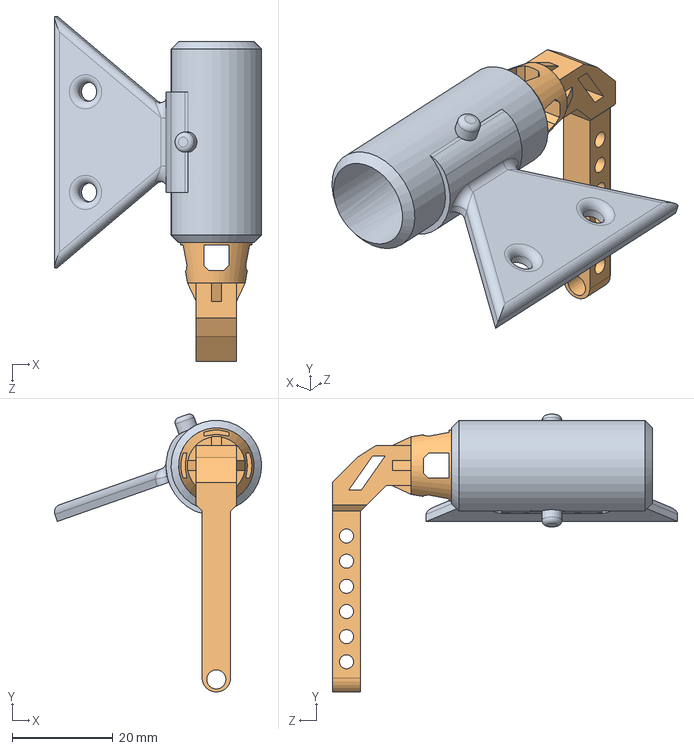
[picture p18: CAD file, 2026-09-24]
鱼尾装配/尾部装配2.SLDASM
41.2 x 55.3 x 68.7 mm
右支撑V2
套筒

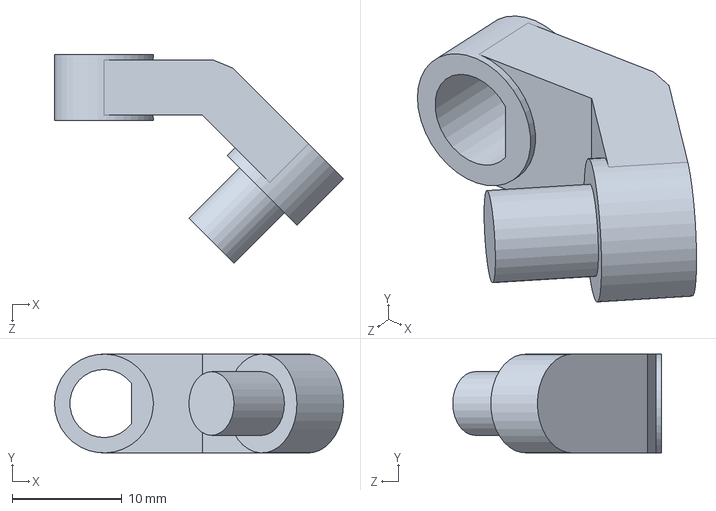
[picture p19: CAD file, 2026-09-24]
鱼尾装配/摇杆.SLDPRT
26.3 x 9.00 x 19.0 mm

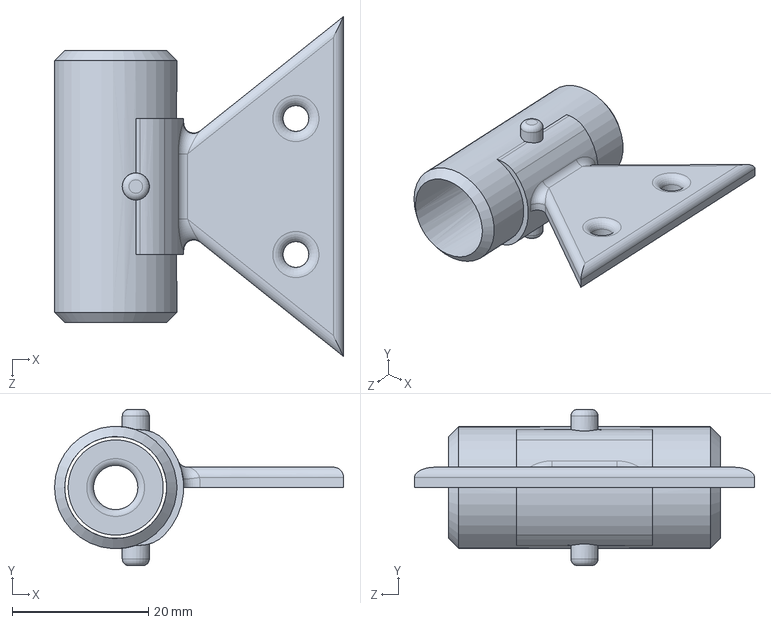
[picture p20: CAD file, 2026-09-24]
鱼尾装配/套筒.SLDPRT
42.5 x 23.0 x 50.0 mm

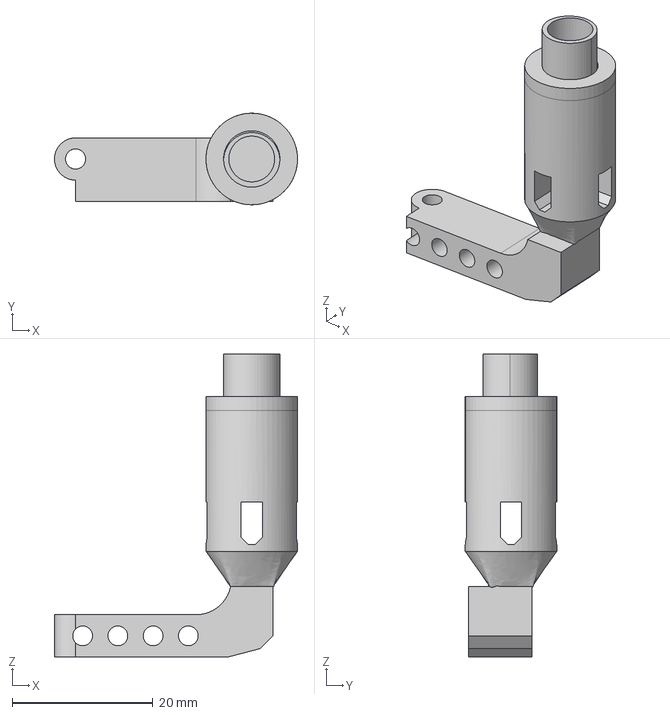
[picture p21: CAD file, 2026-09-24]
鱼尾装配/尾部左支撑V6F.step
34.5 x 13.0 x 43.0 mm

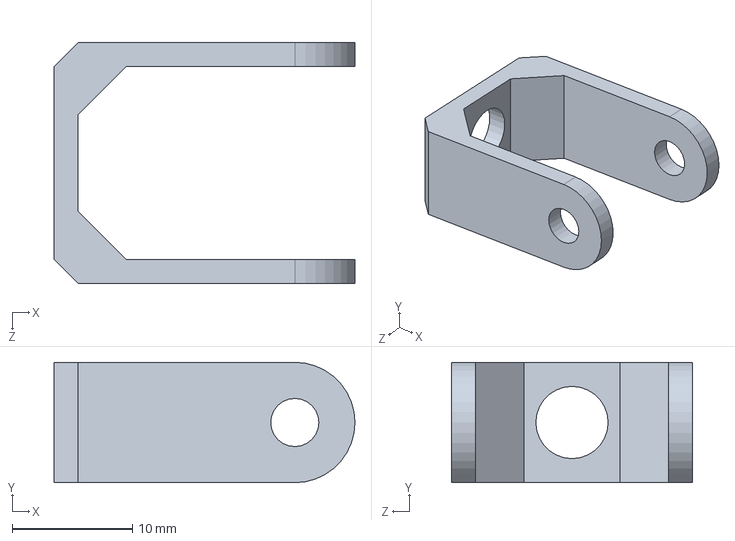
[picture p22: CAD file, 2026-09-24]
鱼尾装配/U型件.SLDPRT
25.0 x 10.0 x 20.0 mm

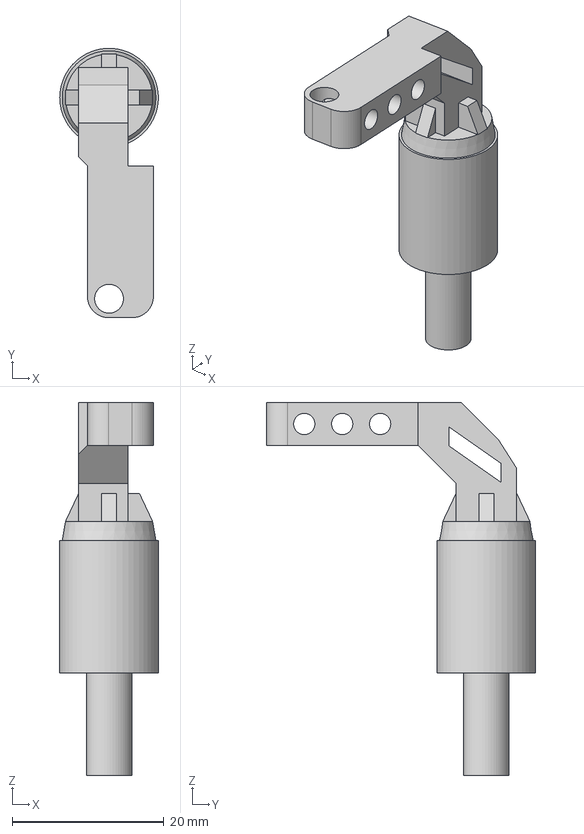
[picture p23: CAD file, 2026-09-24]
鱼尾装配/右支撑V4F.step
13.0 x 35.5 x 49.2 mm

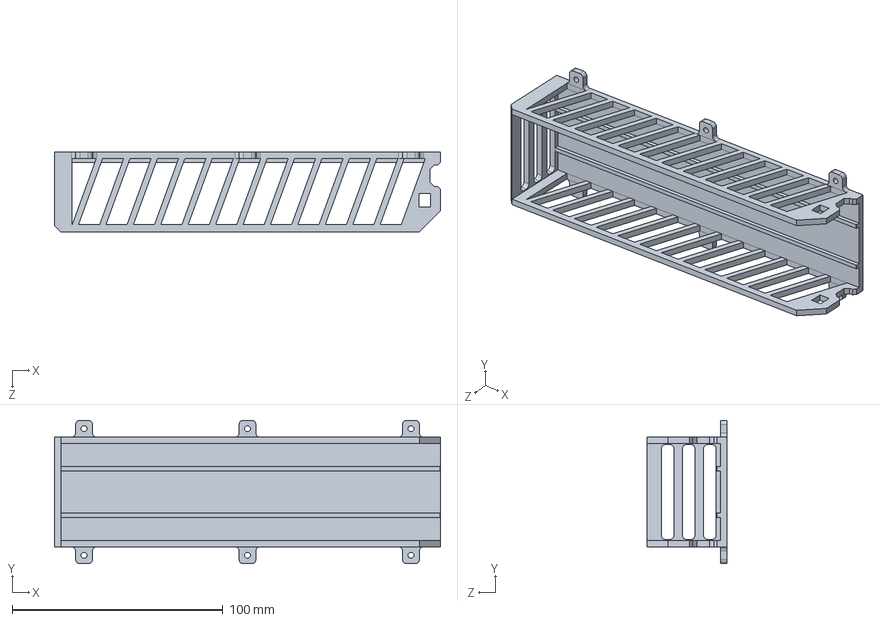
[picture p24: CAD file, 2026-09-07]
鱼尾装配/快拆架.SLDPRT
183.0 x 68.0 x 38.0 mm

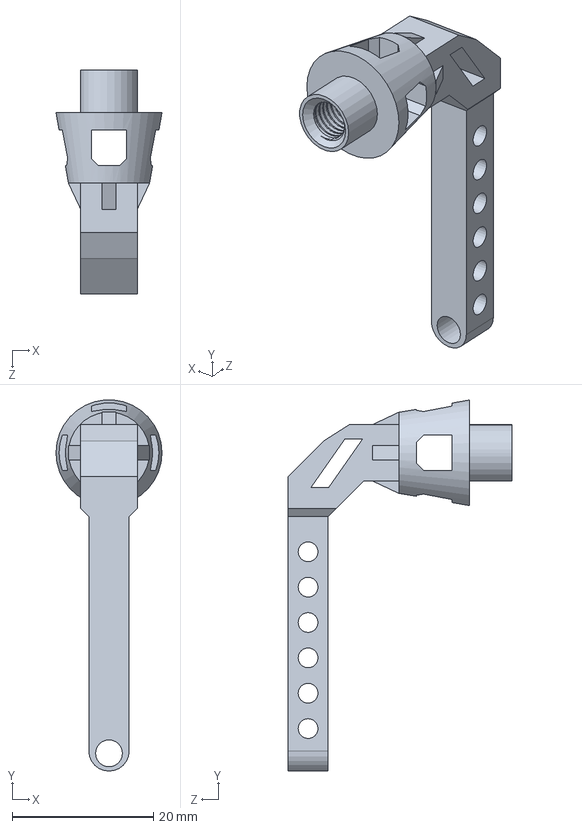
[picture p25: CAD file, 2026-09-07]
鱼尾装配/右支撑V2.SLDPRT
15.0 x 52.5 x 31.7 mm

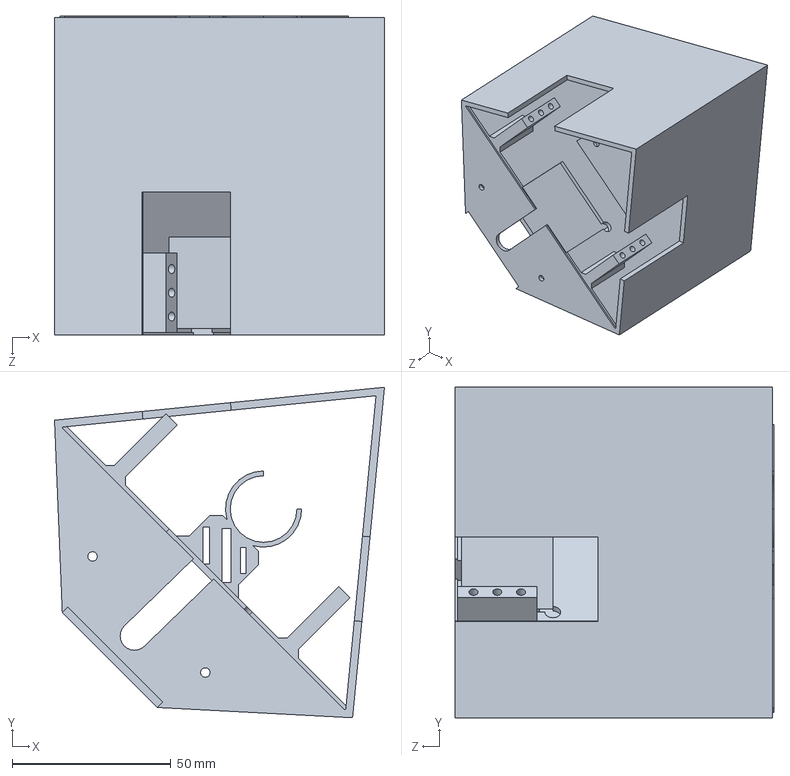
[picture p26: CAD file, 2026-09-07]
鱼尾装配/鱼体第二关节.step.SLDPRT
104.0 x 104.2 x 100.5 mm

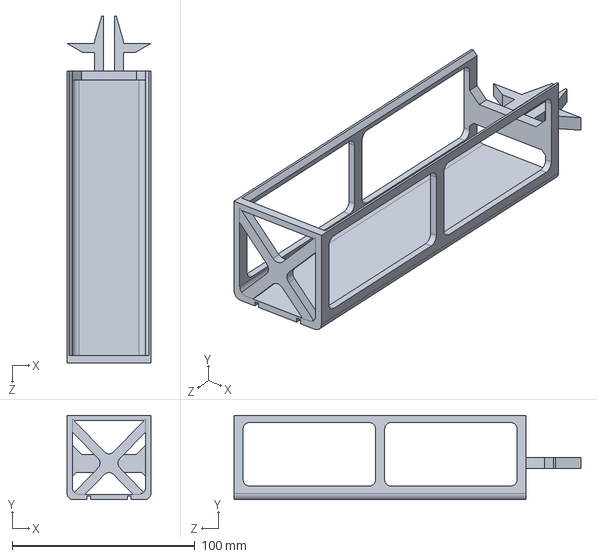
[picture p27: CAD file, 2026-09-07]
鱼尾装配/防水盒快拆.SLDPRT
46.0 x 46.3 x 190.0 mm

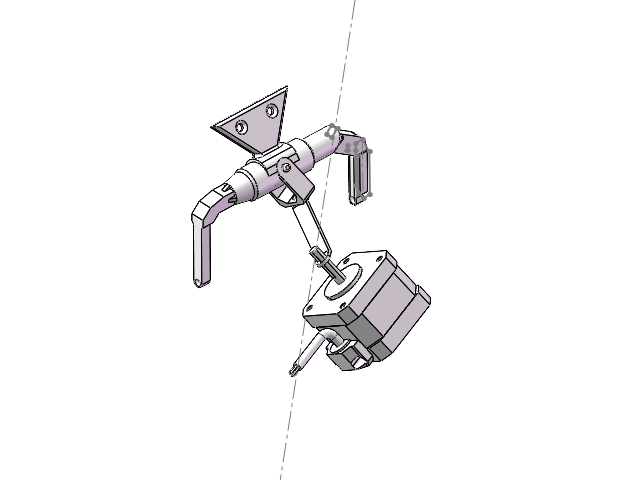
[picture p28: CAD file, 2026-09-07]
鱼尾装配/测试装配.SLDASM
套筒
U型件
尾部支撑
右支撑V2
遥杆
____ 42_________42HS34-FS.STEP
____ 42_______42HS34-FS.STEP
cross recessed cheese head screws gb_GB_CROSS_SCREWS_TYPE2 M3X25-25 H type-N_1.STEP x 4
____ 42____17mm_42HS34-FS.STEP
42_________1.STEP

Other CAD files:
鱼尾装配/moto shef.SLDPRT

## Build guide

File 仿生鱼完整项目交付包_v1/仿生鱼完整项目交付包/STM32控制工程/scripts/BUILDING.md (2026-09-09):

# 固件构建与 CubeMX 工作约定

固件只有一条构建路径：`CMakeLists.txt`。`build.py` 和保留的旧 `build_firmware_direct.sh` 都调用它；旧脚本不再维护另一份源列表，也不再注入 `assert_param.h`。

## 固定依赖

| 组件 | 基线 |
| --- | --- |
| STM32CubeF1 | v1.8.6，与 `bionic_fish.ioc` 相同；Git commit `42472d601caa457b02d849c7de5f9792629ee324` |
| Arm GNU Toolchain | 13.3.Rel1，目标 `arm-none-eabi` |
| CMake | 3.31.8；工程最低要求 3.20 |
| Ninja | 1.12.1 |
| Python | 3.9 或更高，仅构建包装脚本需要 |
| 主机测试 C 编译器 | GCC / Clang；本机验证使用 MinGW-w64 GCC 8.1.0 |

下载地址、Windows 工具归档 SHA-256、CubeF1 及两个必要子模块的 commit 均固定在 `dependencies.lock.json`。CMake/Arm 校验值来自官方发布的 SHA-256 文件；Ninja 校验值来自固定版本官方发布归档的实算。HAL/CMSIS 保留在用户缓存，不提交到业务仓库。CMake 会拒绝其他 CubeF1 版本的 `package.xml`。

## Windows 首次构建

在 `STM32控制工程` 目录执行，先确保 Python 和 Git 可用：

```powershell
python scripts/build.py firmware --bootstrap
python scripts/build.py host --bootstrap --host-cc C:/path/to/native-gcc.exe
```

`--bootstrap` 从官方源下载校验后的工具和固定版本 CubeF1，默认缓存为 `%LOCALAPPDATA%/bionic-fish-build`。首次下载需要网络及磁盘空间；已有缓存会复用。所有 PATH 设置仅传给本次子进程，不安装驱动、不修改用户全局环境、不自动烧录。第二次无需 `--bootstrap`。

宿主测试不要指定 `arm-none-eabi-gcc`；它不能生成可在电脑运行的测试程序。若本机 `gcc` 已正确配置，`--host-cc` 可以省略。Release/MinSizeRel 测试也保留断言。

## 已有工具、Linux 和 macOS

同一 Python 包装脚本支持所有平台；Windows 自动下载的二进制不用于其他平台。Linux/macOS 安装对应平台的 Arm GNU 13.3.Rel1、CMake 和 Ninja，传入目录，或将工具加入当前终端 PATH：

```sh
python3 scripts/build.py firmware --bootstrap --toolchain-bin /opt/arm-gnu-toolchain/bin
python3 scripts/build.py host --host-cc /usr/bin/gcc
```

在非 Windows 平台，`--bootstrap` 仅获取固定版本 CubeF1。也可以直接指定已安装的 v1.8.6：

```sh
python3 scripts/build.py firmware --cube-path /path/to/STM32Cube_FW_F1_V1.8.6 --toolchain-bin /path/to/arm/bin --cmake /path/to/cmake --ninja /path/to/ninja
```

不使用 Python 的等价入口仍是 CMake：

```sh
cmake -S . -B build-firmware -G Ninja -DCMAKE_TOOLCHAIN_FILE=cmake/arm-none-eabi-gcc.cmake -DARM_TOOLCHAIN_BIN=/path/to/arm/bin -DSTM32CUBE_F1_PATH=/path/to/STM32Cube_FW_F1_V1.8.6 -DBIONIC_FISH_BUILD_FIRMWARE=ON -DBIONIC_FISH_BUILD_HOST_TESTS=OFF -DCMAKE_BUILD_TYPE=MinSizeRel -DBIONIC_FISH_WERROR=ON
cmake --build build-firmware --parallel
```

换编译器或生成器时使用新的 `--build-dir`，不要复用另一工具链的 CMake 缓存。

## 输出与验收

固件输出在忽略的 `build-firmware/`：`bionic_fish.elf`、`bionic_fish.bin`、`bionic_fish.map`。Python 包装脚本额外生成 `build-info.json`，记录编译器、CMake、CubeF1、源提交及是否有未提交修改、产物长度和 SHA-256。它不会把带未提交修改的产物误称为该 Git 提交的干净构建。

链接脚本限定 STM32F103C8 的 64 KiB Flash、20 KiB SRAM，并预留 0x200 堆及 0x800 栈；超区会使链接失败。链接日志打印内存使用，`arm-none-eabi-size` 打印段统计。通过链接只证明静态容量合规，不替代堆栈运行峰值或目标板波形验证。烧录操作按 `scripts/README.md` 单独执行。

Arm GNU 13.3.Rel1 的 `newlib-nano/nosys` 在库解析阶段会报告 `_close`、`_lseek`、`_read`、`_write` 未实现；基线干净构建已确认这些符号随后被链接垃圾回收，未保留在最终 ELF。串口收发由 BSP 实现。构建保留这四条链接诊断；`BIONIC_FISH_WERROR` 检查的是编译器告警。Flash 初始化函数指针表显式标为只读，生成的 ELF LOAD 段分别为 RX / RW；链接脚本本身也列为重链接依赖。

## CubeMX 再生成政策

`Core/` 是受维护的 HAL 风格适配层，**禁止在交付源码目录直接点击 Generate Code 并将结果视为可烧录版本**。CubeMX 的 KeepUserCode 只保护 USER CODE 区，无法保留自定义的完整时钟映射、MSP、安全 GPIO 初始化、HAL 配置和构建源列表。

1. 将 `bionic_fish.ioc` 复制到仓库之外的独立临时目录，使用 STM32CubeF1 v1.8.6 生成。
2. 查看生成文件与受维护 `Core/` 的差异，只合并本次需要的引脚/外设变更；更新 `.ioc` 与 `app_config.h` 的同一配置。
3. 保留 `main.c` 中已标记的 Includes、PD、2、3、4 和 Error_Handler_Debug 区域。必须存在 `BSP_Time_Init`、`App_Init`、循环中的 `App_Process`，以及 TIM4、UART RX/TX/Error 回调向 BSP 的转发。
4. 特别复查两桥启动 coast、舵机初始脉宽、TIM4 更新中断、USART2/3、SWD 和两条软件 I²C 的开漏配置；保留标准 `assert_param` 定义与 `Core/Src/assert.c`。
5. 完整执行 host 测试和固件交叉构建，再执行目标板空载验收。

业务接入 USER CODE 标记用于辅助合并，并不表示当前整个 `Core/` 已通过 CubeMX 无损再生成验收。官方行为参见 [STM32CubeMX UM1718](https://www.st.com/resource/en/user_manual/dm00104712-stm32cubemx-for-stm32-configuration-and-initialization-c-code-generation-stmicroelectronics.pdf)。

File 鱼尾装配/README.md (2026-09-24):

# 鱼尾装配 · 结构件开源

本目录是仿生鱼**尾段结构**的可发布零件集，供复刻者参考装配与打印。所有零件均为自主设计，经多轮迭代收敛到当前版本。

单位 **mm**。SolidWorks 原生件为 `SLDPRT` / `SLDASM`，通用交换格式为 `step`。

<p align="center">
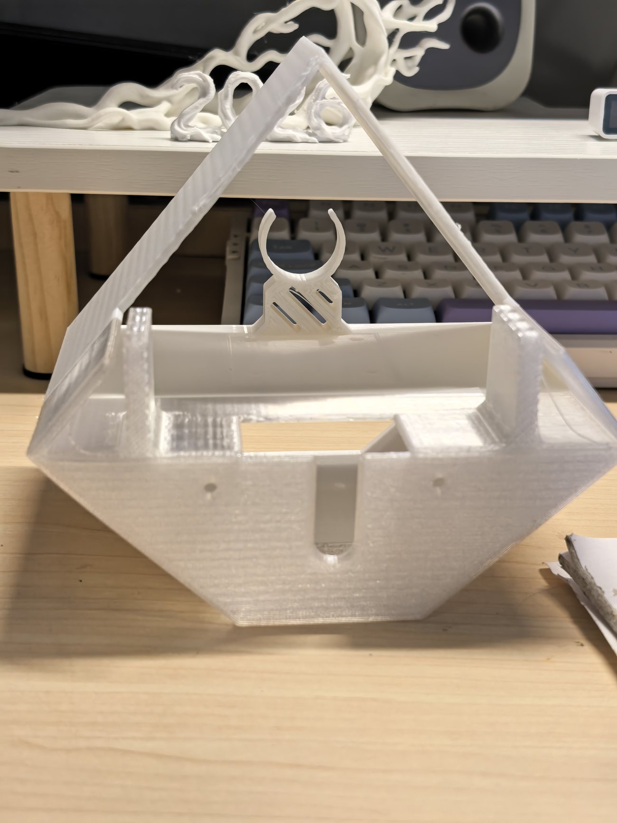
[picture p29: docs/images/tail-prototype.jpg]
尾段支撑件与传动件打印实拍
  
</p>
<p align="center"><em>打印完成的尾段支撑件与传动件实拍 —— 支撑件已带加强筋，与曲柄摇杆、尾鳍座配合</em></p>

## 零件清单

| 文件 | 作用 | 状态 |
| --- | --- | --- |
| `尾部左支撑V6F.step` | 尾段左侧承载支撑，V6 系列最终版 | **当前版本** |
| `右支撑V4F.step` | 尾段右侧承载支撑，V4 系列最终版 | **当前版本** |
| `右支撑V2.SLDPRT` | 右侧支撑早期版，保留作对比 | 历史版本 |
| `套筒.SLDPRT` | 曲柄摇杆传动套筒 | **当前版本** |
| `摇杆.SLDPRT` | 曲柄摇杆机构摇杆 | **当前版本** |
| `U型件.SLDPRT` | 尾段连接件 | **当前版本** |
| `moto shef.SLDPRT` | 电机安装座 | **当前版本** |
| `鱼体第二关节.step.SLDPRT` | 体/尾分段装配关节 | **当前版本** |
| `快拆架.SLDPRT` | 尾部快拆结构 | **当前版本** |
| `防水盒快拆.SLDPRT` | 防水盒快拆接口 | **当前版本** |
| `尾部装配2.SLDASM` | 尾段装配体（SolidWorks） | 参考装配 |
| `测试装配.SLDASM` | 早期测试装配体 | 历史版本 |

## 传动与推进方案说明

尾段采用**曲柄摇杆式**传动，由 **370 直流减速电机**驱动。

> ⚠️ **已废弃方案**：早期设计使用「42 两相双极步进电机 + 软件四拍换相」驱动尾段，后因失步不可观测、TB6612 驱动余量偏紧等问题，改为直流减速电机方案。相关步进零件（`42HS34-FS.STEP`、`步进支架.step`）**未包含在本目录中**，请勿据此推断当前硬件参数。

## 迭代说明

尾部支撑是尾段设计中迭代最多的零件，经 V2 → V3R → V4R → **V6F / V4F** 多轮收敛。演进过程中反复权衡了传动力臂、支撑刚度与 3D 打印方向：早期版本偏重外形贴合，后期版本为保证电机负载下的结构刚性而增加加强筋与壁厚。

## 打印与装配提示

- 支撑件为主要承力件，建议使用 **PETG**，壁厚不低于 3.2 mm，填充率 40% 以上。
- 装配前请核对本目录版本号与自身硬件方案是否一致，**避免混用历史版本**。
- 关节与快拆件建议先试打印单件确认配合间隙，再批量打印。
- 部分零件的装配间隙与止口需根据实际打印精度微调。

## 边界说明

- 本目录为**结构件发布集**，不含完整装配工艺文件与公差标注。
- 完整建模工作区（含历史版本、第三方素材）不随仓库发布。
- 复刻时请结合 [README 第四章](../README.md#四外观与结构设计) 一并阅读。

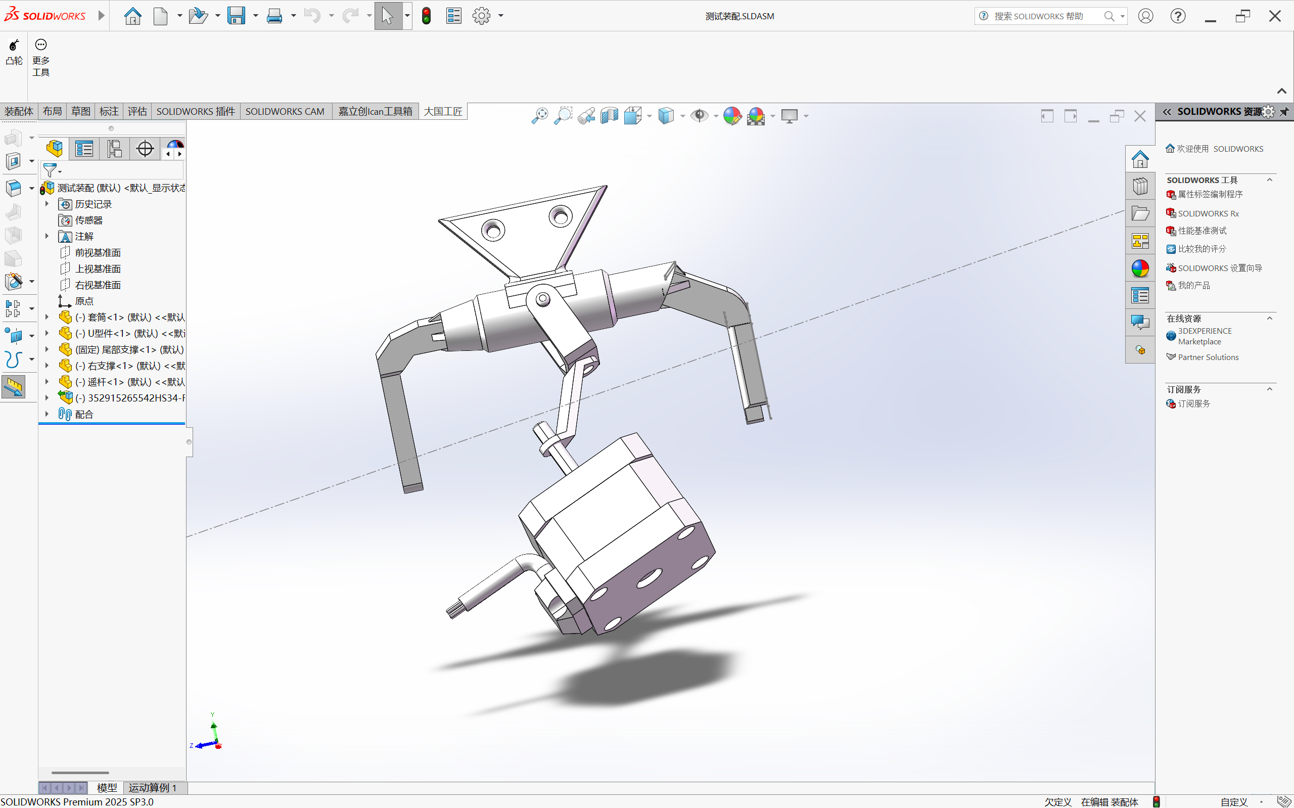
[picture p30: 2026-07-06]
实物图片/装配体.png

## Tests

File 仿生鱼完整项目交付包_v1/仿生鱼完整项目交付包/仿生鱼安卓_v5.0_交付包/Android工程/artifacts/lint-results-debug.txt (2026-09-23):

C:\Users\Lishi\Documents\Codex\2026-09-02\stm32f103c8t6-stm32f1-hal-cubemx-ssd1306-oled\outputs\bionic-fish-android-controller-v0.5.0\gradle\wrapper\gradle-wrapper.properties:3: Warning: A newer version of Gradle than 8.13 is available: 8.14.5 [AndroidGradlePluginVersion]
distributionUrl=https\://services.gradle.org/distributions/gradle-8.13-bin.zip
                ~~~~~~~~~~~~~~~~~~~~~~~~~~~~~~~~~~~~~~~~~~~~~~~~~~~~~~~~~~~~~~

   Explanation for issues of type "AndroidGradlePluginVersion":
   This detector looks for usage of the Android Gradle Plugin where the
   version you are using is not the current stable release. Using older
   versions is fine, and there are cases where you deliberately want to stick
   with an older version. However, you may simply not be aware that a more
   recent version is available, and that is what this lint check helps find.

C:\Users\Lishi\Documents\Codex\2026-09-02\stm32f103c8t6-stm32f1-hal-cubemx-ssd1306-oled\outputs\bionic-fish-android-controller-v0.5.0\app\build.gradle.kts:57: Warning: A newer version of androidx.core:core-ktx than 1.17.0 is available: 1.18.0 [GradleDependency]
    implementation("androidx.core:core-ktx:1.17.0")
                   ~~~~~~~~~~~~~~~~~~~~~~~~~~~~~~~

   Explanation for issues of type "GradleDependency":
   This detector looks for usages of libraries where the version you are using
   is not the current stable release. Using older versions is fine, and there
   are cases where you deliberately want to stick with an older version.
   However, you may simply not be aware that a more recent version is
   available, and that is what this lint check helps find.

C:\Users\Lishi\Documents\Codex\2026-09-02\stm32f103c8t6-stm32f1-hal-cubemx-ssd1306-oled\outputs\bionic-fish-android-controller-v0.5.0\app\build.gradle.kts:69: Warning: A newer version of org.jetbrains.kotlinx:kotlinx-coroutines-android than 1.10.2 is available: 1.11.0 [NewerVersionAvailable]
    implementation("org.jetbrains.kotlinx:kotlinx-coroutines-android:1.10.2")
                   ~~~~~~~~~~~~~~~~~~~~~~~~~~~~~~~~~~~~~~~~~~~~~~~~~~~~~~~~~
C:\Users\Lishi\Documents\Codex\2026-09-02\stm32f103c8t6-stm32f1-hal-cubemx-ssd1306-oled\outputs\bionic-fish-android-controller-v0.5.0\app\build.gradle.kts:75: Warning: A newer version of org.jetbrains.kotlinx:kotlinx-coroutines-test than 1.10.2 is available: 1.11.0 [NewerVersionAvailable]
    testImplementation("org.jetbrains.kotlinx:kotlinx-coroutines-test:1.10.2")
                       ~~~~~~~~~~~~~~~~~~~~~~~~~~~~~~~~~~~~~~~~~~~~~~~~~~~~~~

   Explanation for issues of type "NewerVersionAvailable":
   This detector checks with a central repository to see if there are newer
   versions available for the dependencies used by this project. This is
   similar to the GradleDependency check, which checks for newer versions
   available in the Android SDK tools and libraries, but this works with any
   MavenCentral dependency, and connects to the library every time, which
   makes it more flexible but also much slower.

0 errors, 4 warnings

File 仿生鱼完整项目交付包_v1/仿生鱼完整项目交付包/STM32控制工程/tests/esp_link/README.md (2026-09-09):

# ESP-AT 链路回归

此测试直接编译生产 `esp_link.c`、`bsp_uart.c`、环形缓冲和 ASCII 解析器。只替换 HAL 与 ESP 对端，不复制一份链路实现。假 HAL 每毫秒最多双向各传 11 字节，ESP 对端必须收齐 AT 命令或 CIPSEND 声明的载荷长度后才回应。测试不连接串口、网络或实板。

在 STM32 控制工程根目录执行（GCC / MinGW）：

```sh
gcc -std=c99 -Wall -Wextra -Werror -pedantic \
  -I tests/esp_link/stubs -I bsp/Inc -I app/Inc -I protocol/Inc \
  tests/esp_link/esp_link_host_test.c bsp/Src/esp_link.c bsp/Src/bsp_uart.c \
  protocol/Src/ring_buffer.c protocol/Src/ascii_protocol.c \
  -o esp_link_host_test
./esp_link_host_test
```

也可运行根工程配置的 CTest 链路目标。Release 构建必须保留测试 `assert`，不能定义 `NDEBUG` 后把检查编译掉。

覆盖：初始化响应归属、非 0 连接 ID、复位与关闭、NONOS/ESP-AT 命令差异、UART 参数核查、ACK 优先与旧 STA 合并、每秒 10 帧持续负载、单个 IPD 内 30 条命令、8 KB 连续 IPD、第二客户端隔离、异常/超长头与截断、UART 环满/ORE/接收重挂失败、清丢失标志时的 ISR 竞争、发送失败/超时、队列饱和、毫秒计数回绕、固定 TCP 空闲超时、在途发送中主动关闭，以及旧关闭响应与新连接交错。

## 当前硬件路径

ESP-01S 为 1 MB Flash 时，优先核对 **NONOS SDK v3.0.4 的 AT 1.7.4 Nano（512+512）**，或同系列 1.7.5 Nano；不要把普通 2 MB AT 包直接套到 1 MB 模块。实际 Flash、AT UART 引脚、115200 8N1 无流控仍须读取实物确认。代码通过 `AT+GMR` 选择 NONOS 1.7.4/1.7.5 的 `_CUR` 命令；已正确安装在相应硬件上的 ESP-AT 2.x 使用其当前命令。它不推断实际 Flash 容量，也不烧录或迁移 ESP 固件。[官方 v3.0.4 发布说明](https://github.com/espressif/ESP8266_NONOS_SDK/releases/tag/v3.0.4)、[官方 AT 镜像说明](https://github.com/espressif/ESP8266_NONOS_SDK/blob/v3.0.4/bin/at/README.md)

每条配置等待各自响应，创建 TCP server 并成功设置 `CIPSTO=3` 后才对外就绪。先探测 AT、软件复位并等待 `ready`，然后关闭回显、识别版本、核查当前 UART，再配置 `app_config.h` 的 AP 名称/密码/IP/端口、DHCP 默认池、普通多连接模式、精简 IPD 头、主动接收和单客户端上限。连续三次配置失败后停止重试，保留诊断并等待模块复位。NONOS 使用不写 Flash 的 `_CUR` 命令；2.x 先设 `SYSSTORE=0`。DHCP 参数顺序不同：NONOS 为 `CWDHCP_CUR=0,1`，2.x 为 `CWDHCP=1,2`。[官方命令对照](https://docs.espressif.com/projects/esp-at/en/release-v2.2.0.0_esp8266/AT_Command_Set/AT_Command_Set_Comparison.html)

## 恢复与容量边界

- UART 丢失、非法 IPD、断开及发送失败统一产生事件；应用消费事件后清协议/序号并停机。旧收发帧不会迁移到新客户端。链路恢复后须重新完成 Android 的 STOP/ACK/STA 握手。
- 服务端固定 `CIPSTO=3`，正常 500 ms 保活不会触发它。ESP8266 ESP-AT 2.2 官方明确服务端单向发送不重置此计时；NONOS 文档支持同一命令，但未明确陈述双向计时细节，因此代码不依赖该细节完成应用保护。已经建立的有效 CMD 会话超过 1000 ms 时，应用还调用 `EspLink_CloseClient()`，立即隔离旧字节并在当前发送事务安全终结后对原 ID 发 `CIPCLOSE`；初次 TCP 握手前不会触发这一应用计时。这样无效流量或单向 STA 不能让失效控制会话一直占住唯一槽位。[ESP8266 2.2 官方 CIPSTO 语义](https://docs.espressif.com/projects/esp-at/en/release-v2.2.0.0_esp8266/AT_Command_Set/TCP-IP_AT_Commands.html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)
- CIPSEND 先发头，收到 `>` 才发精确载荷，收到 `SEND OK` 才发下一事务；不额外添加 CRLF、不使用固定冷却限制吞吐。ACK/ERR 用原有固定存储合并完整帧，STA 只保留最新一帧；容量耗尽时安全断链，不假装 ACK 已送达。
- IPD 长度与 ASCII 单帧长度分离，按流处理，帧头限制数字位数及整数溢出；500 ms 是 IPD 字节间空闲上限，不是整段持续时间。固定内存并非无限吞吐承诺；超过 UART/应用处理能力的流量仍会触发可见丢失和停机。
- **不能证明 ESP 已退出 CIPSEND 数据阶段时，禁止盲发 AT+RST 或 +++。** 700 ms 发送超时先使应用断链停机；随后最多等 5 秒获取迟到的提示/终结响应。迟到 `>` 可用等长空格加 LF 完成本次已声明的载荷，再在终结响应后复位；若无终结证据，`EspLink_ResetNeeded()` 锁存为真，`LastError()` 指示检查/复位 ESP 的电源或 EN，直到收到真实 `ready`。MCU 单独复位后连 AT 探测都未回应，也不假定 ESP 的旧数据阶段已结束。该板未提供 ESP 硬件复位控制脚，软件无法承诺这类故障自动恢复。[Espressif CIPSEND 与仅透传可用的 +++](https://docs.espressif.com/projects/esp-at/en/release-v2.2.0.0_esp8266/AT_Command_Set/TCP-IP_AT_Commands.html)

宿主通过不等于实板通过。实板仍需验证电源、交叉接线、实际 AT 镜像/引脚、AP DHCP、Android Wi-Fi 绑定、STOP 握手、持续控制及掉电/串口错误停机。

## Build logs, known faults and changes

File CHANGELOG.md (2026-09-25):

# 仿生鱼工程 - 更新日志

> 自动维护，每天由星尘光检查项目更新情况并记录。
> 若某天漏检，次日会自动补写遗漏的更新内容。
> 项目开源地址：[Chemcrin/bionic-fish: CTGU 天问 自然与设计 仿生鱼设计与构想](https://github.com/Chemcrin/bionic-fish)

---

## v1.0.0 — 正式版发布（2026-09-25）🚀

> 首个正式版。本条汇总 v0.3.1 发布之后的全部工作：整机完成实际下水运行、项目口径调整为项目组协作、交付包升级为 v1、采购发票移出版本控制。

### 一、交付包升级为 v1 📦

- 目录 `仿生鱼完整项目交付包_v0.5/` → **`仿生鱼完整项目交付包_v1/`**，README、复刻指南、电气设计说明与烧录脚本中的引用路径全仓库同步
- 保留并恢复关键交付文档：`交付说明.md`、`原始资料/STM32拓展板_2026-08-26_引脚分配.md`、
  `STM32控制工程/代码审查问题清单_2026-09-08.md`、`ESP01S_AP_UDP_Bridge/README.md`
- 交付包内容：STM32 控制工程（固件源码 + 构建/烧录脚本 + 说明文档）、仿生鱼安卓 v0.5.0 交付包（Android 工程 + APK + 安装说明）

### 二、项目口径与验证状态 📌

- 署名口径由「一人主导 / 全栈单人造」调整为「**项目组主导、组员协作、AI Agent 辅助**」
- 验证状态由「尚处于台架验证阶段，未完成整机下水验收」更新为「**已在泳池 / 静水环境完成整机下水运行实测**」：密封、配重、姿态与基本机动（前进、转向、安全停机）均已验证
- 新增说明：软件层证据（host 回归、Android 单元/仪器测试、实板烧录与 USART3 诊断）与整机下水是**两套独立证据**；文中「待实板 / 需实测」条目指尚未逐项定量标定（如堵转电流、TB6612 温升、动密封长期衰减），不代表整机未下水
- 开发历程由三阶段扩为四阶段，新增「**实机下水**」阶段；下水流程补充第 8 步（下水运行要求）

### 三、仓库整备 🧹

- **采购发票不再纳入版本控制**：`.gitignore` 忽略 `发票/`，并已将历史中已跟踪的发票内容从仓库移除（发票含抬头、税号等敏感信息，不适合公开仓库）
- 新增仓库根目录「一键编译 + 烧录」脚本 `烧录脚本.ps1`：CMake + Ninja + arm-none-eabi-gcc（WERROR=ON）编译，ST-Link / SWD 烧录校验并复位运行，工程路径相对脚本自身解析
- 开源尾段结构件 `鱼尾装配/`；建模工作区、课程资料、讲演实物图与参考素材继续保持不入库

---

## v0.5.0 — TCP 控制链路修复（2026-09-09）

- 当前交付收敛为 STM32F103C8T6 + ESP-01S AT/TCP + Android；HarmonyOS 暂停，自定义 ESP 透明桥移入历史目录。
- 修复 AT 初始化、连接 ID、完整发送、接收丢失、安全断链、半开连接释放；保留固定内存，ACK/ERR 优先、STA 只保留最新值。
- 推进简化为固定低速开/停：默认10%PWM、50ms四拍换相；删除RPM换算、每转步数和参数确认门禁。前进连续运行，停止/失联释放两相，保活和调舵不重置节拍。
- 修复姿态错误恢复、OLED后台重初始化；删除重复状态/兼容接口及关闭失联停机的开关。按键及OLED页面布局保持本轮范围不变，仅更新推进状态文字。
- 构建收敛为单一 CMake 源列表，固定依赖，恢复 HAL 断言配置并记录 CubeMX 独立目录合并政策。
- 修正烧录脚本的SWD频率参数；默认普通软件复位连接，NRST复位下连接改为显式选项，ELF/HEX使用内嵌加载地址。
- Android 源码版本0.3.2/versionCode5；取消RPM档位选择，接受RPM为NA及step_on驱动状态。旧UDP设置迁移且实际入口拒绝UDP。
- 固定工具链，补齐从旧APK恢复的主题常量并统一Java/Kotlin目标17；本轮固定低速版本17/17 CTest、Arm构建、56/56 Android单元测试、23/23 MuMu设备测试通过，lint0错误；结果见工程验收记录。实板验收另行记录。

## v0.1.0 — 项目初始化（2026-05-25）

- 创建仿生鱼工程项目，初始化 Git 仓库
- 添加 README.md，明确项目定位：面向水下任务演示的仿生虎鲸（体长 50-60cm）
- 添加 .gitignore、LICENSE、需求文档
- 添加初始项目计划书（v1）

## v0.1.1 — 项目计划迭代 & 阶段A硬件清单（2026-05-29）

- 更新项目计划书，新增阶段A硬件采购清单
- 明确硬件平台：STM32F103ZET6 + ESP32 无线中继

## v0.1.2 — 通信方案升级 & 虎鲸定型（2026-05-30）

- v3 版本：通信方案从有线改为 ESP32 无线中继（2.4G 背鳍天线）
- v3.1 版本：确定仿生虎鲸外形（50-60cm）、防水电机曲柄摇杆推进、舵机齿轮组联动背鳍与尾腰转向、腹鳍独立控制
- 采购清单迭代至 v4 版本

## v0.1.3 — 采购清单补充 & 清理（2026-06-04）

- 补充采购清单 v3、项目计划书 v3.2
- 清理冗余整理版文件

---

## v0.1.4 — 项目同步与采购清单更新（2026-06-17）

- 项目同步，更新采购清单
- 里程碑：四六级备考期后首次恢复提交

---

## v0.1.5 — 机构件建模 & HarmonyOS 上位机开发（2026-06-25）

### 本周进展（6月22日 — 6月25日）

**一、曲柄摇杆机构 — 参数化设计与导出 ✅**

基于 CADQuery 建立完整的曲柄摇杆机构模型，关键参数已标定并写入 `parameters.txt`：
- 固定轴距 O₁-O₂：44 mm
- 曲柄半径 O₁-A：10 mm
- 连杆长度 A-B：35 mm
- 摇杆长度 O₂-B：26 mm
- 装配曲柄角：135°，对应摇杆输出角 74.59°
- 销孔直径：Φ3.2 mm，尾轴间隙孔：Φ5.3 mm

共导出 7 个机构件 STEP 文件（含序号），可直接用于 3D 打印或 CNC 加工：
1. `00_crank_rocker_assembly.step` — 整机装配总图
2. `01_frame_tail_motor_support.step` — 机架/尾部/电机支撑座
3. `02_motor_crank.step` — 电机曲柄
4. `03_connecting_rod.step` — 连杆
5. `04_tail_rocker.step` — 尾部摇杆
6. `05_tail_shaft.step` — 尾轴
7. `06_tail_output_horn.step` — 尾部输出摇臂
8. `07_m3_joint_pin.step` — M3 关节销轴（×4）

Python 参数化生成脚本：`crank_rocker_cadquery.py`

**二、U型件建模与装配 🔧**
- 根据曲柄摇杆机构接口，完成 U 型件建模（U 间距 14 mm，竖直杆长 15 mm，腿宽 15 mm，厚 2 mm，顶部半圆 R7.5 mm，中心 Φ4 通孔）
- 导出 U 型件 STEP + STL，可在 SolidWorks 中与曲柄摇杆配合验证

**三、支撑结构与外壁建模 🖨️**
- `尾部支撑_v2.step / .stl` — 尾部支撑迭代至 v2 版
- `右支撑.SLDPRT / .stl` — 右侧支撑件（SolidWorks）
- `测试装配.SLDASM` — SolidWorks 装配验证

**四、虎鲸外壳建模 🐋**
- `虎鲸外壳_500x200.step / .stl` — 外壳主体（500×200 比例虎鲸外形）
- `虎鲸外壳_壳体_500x200.stl` — 壳体镂空版本（可直接切片打印）

**五、HarmonyOS 上位机开发 📱**
- 完成仿生鱼 HarmonyOS 上位机工程源码（ArkTS / Stage 模型），位于 `BionicFishHarmony/`
- **通信层**：`FishSocketClient.ets` 封装官方 `@kit.NetworkKit` WebSocket，连接 ESP32-S3 网关（`ws://192.168.4.1/ws`）
- **协议层**：`FishProtocol.ets` 定义 JSON 帧规范，支持控制帧（throttle/yaw/pitch/mode）、参数帧（tail_amp_limit/servo_trim等）、心跳帧与 ACK 应答
- **UI 层**：`Index.ets` 主控制台，包含深色水下沉浸风 UI、连接管理、方向控制、模式切换、参数调节、遥测显示、固定急停入口
- **视觉设计**：ArkUI 原生毛玻璃（`backgroundBlurStyle`）、连续脉冲动画、大触控面积、沉浸深色光感
- 暂未打包为 `.hap`，需在 DevEco Studio + HarmonyOS SDK API 12+ 环境中构建
- README.md 已同步更新构建步骤与兼容提醒

### 待办
- 曲柄摇杆机构运动学仿真（角度、位移、急回特性分析）
- 各零件干涉检查与配合优化
- 装配体爆炸图与 BOM 表输出
- 采购清单与实际到货零件核对
- 鸿蒙上位机 `.hap` 打包与真机调试
- ESP32 WebSocket 网关固件联调

---

## v0.1.6 — 实物图片 & 尾部支撑建模更新（2026-07-06）

- 📸 新增实物图片，展示项目实际制作进度
- 更新尾部支撑建模至新版本

---

---

## v0.2.0 — 追鲨一号外壳复刻 & STM32 拓展板设计（2026-08-22 ~ 09-02）

> 8 月下旬项目恢复活跃，三大方向并行推进：追鲨一号外壳复刻、SolidWorks 结构建模迭代、STM32 拓展板设计。

### 一、PCB 参考图整理（8/22）📷

- 裁剪 ESP / MCU / 电源 / 稳压 / 开关 / USB / 串口等模块参考图（`crop_*.png` 共 7 张）
- 8/26 补充 PCB 参考图：`pcb_esp.png`、`pcb_mid.png`

### 二、追鲨一号外壳复刻 v1（8/25-8/26）🐋

- 视频参考帧提取：`video_extract_probe.py`、`extract_keyframes.py`（8/25 晚）
- 参考图整理：`curate_refs.py` + `shark_chaser_modeling_refs/`
- `mesh_to_step.py` 网格→STEP 转换，生成三段式外壳复刻（`建模/追鲨一号外壳复刻_v1/out/`）：
  - `head_shell.step`（头部）、`body_shell.step`（身体）、`tail_shell.step`（尾部）
  - `Zhuisha_No1_Assembly.step`（总装） + `zhuisha_no1_v1.step`
- 配套 README 说明复刻流程

### 三、SolidWorks 结构建模迭代（8/23 ~ 9/1）🔧

- 尾部支撑迭代至 **V4R**（8/23）
- **鱼体第二关节** draft 建模（8/23），后续导出 `draft2.STEP / .stl`
- **虎鲸三视图设计稿**（8/28），8/30 导出主视图 / 俯视图 / 左视图
- 新增零件：`地瓜！？.SLDPRT`（8/30）
- 快拆结构方案：`防水盒快拆.SLDPRT`（8/31）、`快拆架.SLDPRT`（9/1）
- 迭代更新：U型件、右支撑V2、测试装配、摇杆主体V1、摇杆底座等

### 四、STM32 拓展板设计（8/26、9/2）🖥️

- 嘉立创 EDA 工程：`STM32拓展板_2026-08-26.epro2`（8/26）
- STM32 天河星核心板方案：`STM32天河星.zip`
- 拓展板 3D 模型：`3D_32拓展_2026-08-26.step`
- 天河星 logo 概念设计：`tianhexing-logo-concept.svg / .png`
- 9/2：解析 epro2 工程（`_epro2_extract/`、`_parsed_components.txt`、`_records.txt`），完成 **引脚分配文档** `STM32拓展板_2026-08-26_引脚分配.md`

### 待办 📋

- 追鲨一号外壳 STEP 转入 SolidWorks 细化，切片打印验证
- 快拆架 + 防水盒快拆装配验证
- STM32 拓展板引脚分配最终核对 → 打样
- ✅ 9/7 全量分批提交（8 个 commit）并推送 GitHub
- 遗留待办：曲柄摇杆运动学仿真、装配干涉检查、爆炸图/BOM、`.hap` 打包、ESP32 网关联调

---

## v0.3.0 — 完整交付包 & Android 上位机（2026-09-07）📦

- **仿生鱼完整项目交付包 v0.3.0**（原交付包目录升级命名）：
  - `Android上位机/`：Kotlin + Jetpack Compose 控制端完整源码、Gradle wrapper、调试 APK（0.2.0 / versionCode 2）、模拟器测试报告与三套真实渲染截图
  - `STM32控制工程/`：STM32F103C8T6 HAL/CubeMX 风格源码、CubeMX 配置与协议测试
  - `交付说明.md`：最终硬件与协议口径（42 步进电机 + TB6612 双 H 桥；N20 已移除；ESP-01S 仅作 Wi-Fi 模块等）+ v0.3.0 版本声明
  - `原始资料/`：STM32 拓展板引脚分配原件
- Android 质量验证：31 个 JVM 单元测试全部通过；13/13 Compose instrumentation 测试通过（Android 15 / API 35 AOSP ATD 模拟器）
- 讲演实物图归档（`讲演实物图.zip`）；根目录补充快拆架模型；`.gitignore` 增加 SolidWorks `~$` 锁文件规则
- ⏸ v0.3.0 交付包未发布，目录已由 v0.3.1 整理版取代（见下）

## v0.3.1 — 交付包整理 & AP 直连发布（2026-09-07）📦

- **仿生鱼完整项目交付包 v0.3.1**（替代 v0.3.0 交付包目录，精简整理）：
  - `STM32控制工程/`：STM32F103C8T6 HAL/CubeMX 源码、固件产物（bionic_fish.bin/.elf/.map）、烧录与调试脚本
  - `仿生鱼安卓AP直连_v0.3.0_2026-09-06/`：AP 直连调试包（仿生鱼控制器_v0.3.0_AP直连.apk，约 19.4MB）、Android 工程源码、界面预览与使用说明
  - `交付说明.md`、`原始资料/`（STM32 拓展板引脚分配原件）
- 移除 v0.2.0 / v0.3.0 旧交付包目录与构建报告等冗余；仓库同步清理不再跟踪的讲演实物图与建模参考素材
- ✅ 已推送 GitHub（Chemcrin）并发布 v0.3.1 Release

## 待观察 📋

- ✅ 8/22-9/2 项目恢复活跃：外壳复刻、结构建模、STM32 拓展板三大方向推进（详见 v0.2.0）
- ✅ 9/7 仓库整理完成并推送（v0.3.1 Release 已发布）
- 遗留待办：曲柄摇杆运动学仿真、装配干涉检查、爆炸图/BOM、`.hap` 打包、ESP32 网关联调

---

*本日志由星尘光自动维护，每日更新。*
*最后检查：2026-09-25 CST*

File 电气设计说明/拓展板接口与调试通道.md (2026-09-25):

# 拓展板接口与调试通道

> 本文件整理自 `STM32拓展板_2026-08-26.epro2` 原理图（依据其 `PAD_NET` 与网络标号）与实装方案。
> 引脚分配与固件侧配置的核对结论见 [`硬件引脚与驱动说明.md`](../仿生鱼完整项目交付包_v1/仿生鱼完整项目交付包/STM32控制工程/硬件引脚与驱动说明.md)。

---

## 一、设计取向

拓展板的设计目标只有一句话：**任何一路模块出问题，都应该是拔下来换掉，而不是拿烙铁上去查。**

| 原则 | 做法 |
| --- | --- |
| 模组化 | TB6612、ESP-01S、JY901S、OLED 均经排针/排母连接，可逐个替换 |
| 可拔换核心 | STM32 核心板以 **32 针母座**插接，可整体取下单独烧录或替换 |
| 全扇出 | UART 与电机、舵机接口**全部引出排针**，杜邦线即可外接新模组 |
| 可观测 | 全链路信号留可测量的测试点；SWD 与串口双通道并行 |
| 可保护 | 输入端 5 A 一次性保险丝兜底短路 |

这套取向沿用 **TI 杯电子设计竞赛**的工程范式：主控 + 功能模组的积木式组合，每个模组独立供电、独立接口、可单独测试。

---

## 二、模块接线总表

| 模块 | 模块接口 | STM32 引脚 | 用途/说明 |
| --- | --- | --- | --- |
| 运行指示灯 | LED | `PC13` | GPIO 输出 |
| TB6612 电机驱动器 | `PWMA`、`PWMB`、`AIN1/AIN2`、`BIN1/BIN2` | `PA0`、`PA1`、`PB12`、`PB13`、`PB14`、`PB15` | `PA0/PA1` 为两路 PWM；`PB12~PB15` 为两路方向控制 |
| 电机端口 1 | `M1+`、`M1-` | 驱动器输出 | 接 370 推进电机 |
| 电机端口 2 | `M2+`、`M2-` | 驱动器输出 | 接 N20 唧筒电机（12 V 版） |
| 舵机 1 | `SIG` | `PA6` | TIM3_CH1 PWM 输出 |
| 舵机 2 | `SIG` | `PA7` | PWM 输出（当前固件未启用） |
| OLED 模块 | `GND`、`VCC`、`SCL`、`SDA` | `GND`、`+3.3V`、`PB8`、`PB9` | 四线接口；软件 I²C |
| ESP-01S 模块 | `GND`、`VCC`、`RXD`、`TXD` | `GND`、`+3.3V`、`PA2`、`PA3` | `RXD`→`PA2`，`TXD`→`PA3`；`RST/EN/IO0/IO2` 悬空 |
| JY901S 陀螺仪 | `SCL`、`SDA` | `PB6`、`PB7` | 软件 I²C，**需外接 4.7 kΩ 上拉** |
| USART1 接口 | RX、TX | `PA9`、`PA10` | 预留串口 |
| USART3 / CH340 | TX、RX | `PB10`、`PB11` | 板载 CH340 转 Type-C，调试日志输出 |
| 按键 1/2/3 | 开关输出 | `PB0`、`PB1`、`PA8` | 低电平有效输入，内部上拉 |
| 下载调试接口 | SWDIO、SWCLK | `PA13`、`PA14` | SWD |
| 外部晶振 | OSC_IN、OSC_OUT | `PD0`、`PD1` | HSE 8 MHz |

### 各模块接线要点

**TB6612**：逻辑电源接 `+3.3V`，电机功率电源接动力轨，逻辑地与功率地均接 `GND`。信号为 `PWMA→PA0`、`PWMB→PA1`、`AIN1→PB12`、`AIN2→PB13`、`BIN1→PB14`、`BIN2→PB15`。两路电机输出接 `M1±` / `M2±`；**电机端不得直接接 STM32 GPIO**。

**JY901S**：`VCC` 接 3.3 V，`SCL`/`SDA` 接 `PB6`/`PB7`。模块的 `RX`/`TX` 未接入 STM32，`D0~D3` 也不是通信引脚。

**OLED**：按 `GND→GND`、`VCC→+3.3V`、`SCL→PB8`、`SDA→PB9` 连接。

**ESP-01S**：`GND→GND`、`VCC→+3.3V`、`RXD→PA2`、`TXD→PA3`，构成 USART2 交叉收发。`RST`、`EN`、`IO0`、`IO2` 在原理图中均未连接，不应误接。

---

## 三、双通道调试：SWD + 板载 CH340

板载 **CH340** 转出 **Type-C 母座**，与 SWD 构成两条**物理独立、互不抢占**的调试通道，可同时接在同一台主机上。

```text
┌───────────────┐   SWD（烧录 / 断点 / 寄存器）  ┌────────────────┐
│   ST-Link     │◄──────────────────────────────►│                │
└───────────────┘                                │  STM32F103C8T6 │
┌───────────────┐   USART3（日志 / V1 状态帧）    │   拓展板        │
│ CH340 (Type-C)│◄──────────────────────────────►│                │
└───────┬───────┘                                └────────────────┘
        │ 两条独立 USB 通道同时挂在同一台主机
┌───────▼────────────────────────────────────────┐
│  AI Agent（可读串口日志 + 可下载固件 + 可复位）   │
└────────────────────────────────────────────────┘
```

**为什么这很重要**：调试的本质是「**改代码 → 烧录 → 看现象 → 再改**」的循环。

- **能烧**：SWD 让工具/Agent 可直接下载固件、复位、halt 查看寄存器，无需人工点 IDE；
- **能看**：CH340 把 `ESP server=… tcp=… reset=… error=…`、`IMU scl= sda= st= probe=`、`STA` 状态帧以**纯文本**吐到串口，工具/Agent 无需摄像头或人工转述即可读到设备真实状态；
- **可交叉验证**：SWD 侧异常时，串口侧仍在独立输出，能立刻区分「固件没跑起来」还是「调试器/接线问题」。

**Type-C 直连的实际收益**：一根普通手机线即可接电脑看串口，不必再找 USB-TTL 转接板，也不必临时接线。这显著降低了「临时想看一下日志」的操作成本。

> 📌 协议选择**可打印 ASCII + 换行分帧**（见 `通信协议.md`）正是为此配合：串口日志可被工具直接解析，而非面对需要额外解码的二进制流。

---

## 四、电源分配

| 模块类别 | 电源轨 | 电压 |
| --- | --- | --- |
| STM32、OLED、ESP-01S、JY901S、CH340 | 3.3 V 逻辑轨（ME6211） | 3.3 V |
| TB6612 逻辑 | 3.3 V 逻辑轨 | 3.3 V |
| TB6612 VM、舵机 | 动力轨（LM2596S） | 按电机/舵机额定值 |

**所有模块必须共地**；电机、舵机功率电源不得由 STM32 GPIO 直接提供。若出现「电机一动、IMU/OLED 就异常复位」，首先怀疑逻辑轨被动力轨的电流冲击污染（共用细走线或地回流路径过窄）。

详见 [`电源方案与电压汇总.md`](电源方案与电压汇总.md)。

---

_整理日期：2026-09-24 ｜ 依据：STM32拓展板_2026-08-26.epro2 与 v1.0.0 实装方案_

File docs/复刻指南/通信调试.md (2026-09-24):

# ② 通信调试

**目标**：让 STM32 ↔ ESP-01S ↔ 手机 这条链路真正跑通，并且**每一步都可观测**。

**完成标志**：手机连上 `BionicFish-AP` 后能完成 STOP/ACK/STA 握手，App 显示「已连接」；串口能看到 `server=1`、`tcp=1`。

---

## 一、链路全貌

```text
┌──────────────┐
│ Android 控制台 │
└──────┬───────┘
       │ Wi-Fi：BionicFish-AP（192.168.4.1）
       │ TCP：端口 9000
┌──────▼───────┐
│  ESP-01S      │  AT 固件 ｜ 纯 SoftAP ｜ TCP Server
└──────┬───────┘
       │ UART0 ↔ USART2，115200-8N1，无流控，交叉收发
┌──────▼───────┐
│ STM32F103C8T6 │
└──────┬───────┘
       │ USART3 → CH340 → Type-C（只发不收，日志与状态帧）
┌──────▼───────┐
│  电脑串口助手  │
└──────────────┘
```

| 参数 | 值 |
| --- | --- |
| SSID / 密码 | `BionicFish-AP` / `12345678` |
| AP / 网关 | `192.168.4.1` |
| 掩码 | `255.255.255.0` |
| 传输 | TCP Server，端口 `9000` |
| Wi-Fi 模式 | `AT+CWMODE=2`（**纯 SoftAP**） |
| 串口 | 115200 / 8N1 / 无流控 |

---

## 二、双通道调试：先把「眼睛」装上

在调通信之前，**必须先能看见设备在说什么**。这就是拓展板把 SWD 与板载 CH340 做成两条独立通道的价值。

| 通道 | 物理接口 | 用途 |
| --- | --- | --- |
| SWD | ST-Link（`PA13`/`PA14`） | 烧录、断点、halt 查寄存器 |
| 串口 | 板载 CH340 + Type-C（`USART3`） | 运行期日志与状态帧，**只发不收** |

**两条通道物理独立、互不抢占，可以同时接在同一台电脑上。**

### 2.1 接入步骤

1. Type-C 线接电脑，在设备管理器中确认多出一个 COM 口（CH340）。
2. 用串口助手打开该端口：**115200 / 8-N-1 / 无流控**。
3. 上电，应看到周期性输出。

### 2.2 应该看到什么

```text
ESP server=1 tcp=0 reset=0 error=OK
```

| 字段 | 含义 |
| --- | --- |
| `server=1` | TCP 服务初始化完成 |
| `tcp=1` | 已有控制客户端连上 |
| `reset=0` | 不需要复位 ESP（`reset=1` 表示需实际复位） |
| `error=OK` | 无错误 |

**这是判断链路状态的第一手信息**，比看手机界面可靠得多。

---

## 三、ESP-01S 配置

### 3.1 固件版本要求

| 项 | 要求 |
| --- | --- |
| AT 版本 | **AT 1.7.4.0**（实物已验证） |
| SDK | SDK 3.0.5-dev (52383f9)，编译于 2020-08-28 |
| 串口参数 | `115273,8,1,0,0` —— 对应约 115200、8N1、无流控 |

确认方法：用 AT 指令查版本，回包应包含上述版本号。**匹配 NONOS 分支**，保留现有固件即可，无需重刷。

> ⚠️ 若你的 ESP-01S 固件版本不同，AT 命令集可能有差异（NONOS AT 1.7.4/1.7.5 与 ESP-AT 2.x 不同）。请核对实际 `AT+GMR` 结果后再继续。

### 3.2 关键配置：Wi-Fi 模式必须是 2

```text
AT+CWMODE=2      ← 纯 SoftAP，必须是 2
```

> 🔴 **绝不能用 `AT+CWMODE=3`（AP+STA 双模）。**
>
> 本项目曾出现过这个回归，后果是**网页完全打不开**：固件从不下发 `AT+CWJAP`，STA 侧永远拿不到凭据，ESP 反复去连 flash 里残留的旧 AP；双模下还要同时维护 DHCP 与多个 socket 槽位，最终**客户端拿不到 IP**。
>
> 若将来确实需要启用双模，**必须同时实现 `AT+CWJAP` 下发**。

### 3.3 其他必要配置

| 指令 | 作用 |
| --- | --- |
| `AT+CIPMUX=1` | 多连接模式（AT 事务需要） |
| `AT+CIPSERVER=1,9000` | 启动 TCP 服务，端口 9000 |
| `AT+CIPSTO=3` | TCP 空闲 3 秒自动断开（**注意：这是已知问题的来源**，见下方） |

**固件的 AT 事务纪律**（复刻时不要绕过）：

- 逐命令下发并**等待自身响应**，不用 `ATE0` 的 OK 代替 `CIPSERVER` 成功。
- 发送先等 `CIPSEND` 的 `>` 提示，再发**声明的准确字节数**，最后等 `SEND OK`。
- 不能确认 ESP 是否仍在等待数据时，**不要把 `AT+RST` 或 `+++` 盲发成载荷**。

> ⚠️ **已知问题：`CIPSTO=3` 会导致 App 连上就断。**
>
> ESP 空闲 3 秒即断开，而 App 在无命令时只 delay、不发帧，于是连接反复重建。可选修复方向：放宽 `CIPSTO`（如 30 s），或让 App 周期发心跳。**本项目未修复此项**，属已知待改进点。

---

## 四、协议联调

协议采用**可打印 ASCII + 换行分帧**，就是为了让复刻者能用任意串口工具直接调试，不必写解码器。

### 4.1 帧格式

```text
<TYPE,key=value,key=value,...>\n
```

- 帧尾必须 `LF`，接收端也接受 `CRLF`。
- 字段值不得含 `<`、`>`、`,`、`=`、换行或 NUL。
- 最大载荷 191 字节（`CFG_PROTOCOL_PAYLOAD_MAX-1`）。
- 组帧超时 250 ms；超时、超长、不可打印字符均丢弃并重新同步。

### 4.2 控制帧（Android → ESP → STM32）

```text
<CMD,seq=12,move=F,turn=R,step_speed=60,servo=-15,m2=R>\n
```

五个基础字段必填，`m2` 选填：

| 字段 | 取值 | 含义 |
| --- | --- | --- |
| `seq` | `0`~`65535` | 16 位序号，用于重复/乱序检测 |
| `move` | `F`/`R`/`S` | **M1（370 推进）** 前进 / 反向 / 停止 |
| `turn` | `L`/`R`/`C` | 左 / 右 / 居中，**必须与 `servo` 符号一致** |
| `step_speed` | `60`/`100` | 占空比挡位：`100`=满速挡（95%）、`60`=低速挡（60%）。**只接受这两个值** |
| `servo` | `-15`~`15` | 相对中位角（度），超范围直接返回 `E_RANGE` |
| `m2` | `F`/`R`/`S` | **选填**，**M2（N20 唧筒）** 推 / 拉 / 停。**缺省 = 停止** |

**两条容易出错的地方**：

1. **`turn` 与 `servo` 的符号必须一致。** `turn=L` 必须配负 `servo`，`turn=R` 配正，`turn=C` 配 `servo=0`；不一致返回 `E_SEMANTIC`，不会静默替你选一个。
2. **`m2` 缺省是「停止」，不是「保持原状态」。** 不写 `m2` 字段，唧筒就会停。

> 📌 `step_speed` 是**历史字段名**（旧步进方案用它选转速档）。字段名与「必填」约束保留以兼容旧客户端，但它现在承载的是**直流电机占空比挡位**，不是步进速度。

### 4.3 状态帧（STM32 → ESP / CH340）

```text
<STA,seq=12,link=1,step_rpm=NA,step_est=NA,step_actual=NA,step_on=1,servo=-15,roll=1.2,pitch=-2.4,yaw=85.7,m1=F,m2=R,err=0>\n
```

周期 200 ms 发送。

| 字段 | 含义 |
| --- | --- |
| `link` | 最近收到有效命令则为 1。**只表示应用控制链路新鲜，不证明 Wi-Fi 或手机真的在线** |
| `step_rpm` / `step_est` / `step_actual` | 固定 `NA`（无编码器，不做转速估算） |
| `step_on` | M1 是否处于运行；**不证明机械轴实际转动** |
| `servo` | 限幅后的**命令角**，不等于实际舵面反馈 |
| `roll` / `pitch` / `yaw` | 有效时输出姿态角；读不到为 `NA`，**不能把 0.0 当有效测量** |
| `m1` / `m2` | 当前已下达的方向 |
| `err` | 当前活动故障位图的十进制值 |

### 4.4 握手流程

```text
1. 手机加入 BionicFish-AP（保持该 Wi-Fi，即使提示无互联网）
2. App 发送完整合法的 STOP CMD
3. 收到同序号 <ACK,seq=N,result=OK>
4. 收到 link=1 的 STA
   → 此时才显示「已连接」
```

> ⚠️ **加入 Wi-Fi 或连上 TCP 本身都不等于握手完成。** 必须走完 STOP → ACK → STA 三步。

### 4.5 手动调试示例

用串口工具直接发（注意行尾 `\n`）：

```text
发送：<CMD,seq=1,move=S,turn=C,step_speed=60,servo=0>
预期：<ACK,seq=1,result=OK>

发送：<CMD,seq=2,move=F,turn=R,step_speed=60,servo=-15,m2=R>
预期：<ACK,seq=2,result=OK>

发送：<CMD,seq=3,move=F,turn=R,step_speed=60,servo=15>
预期：<ERR,seq=3,code=E_SEMANTIC>     ← turn=R 配了负 servo
```

---

## 五、故障定位

### 5.1 定位思路

**分层判断，不要一次怀疑所有环节。**

```text
串口有输出吗？
  ├─ 没有 → MCU 层面问题（供电/时钟/烧录）→ 回 [硬件制造.md](硬件制造.md)
  └─ 有 → 看 server= 字段
            ├─ server=0 → ESP 初始化失败 → 查 AT 固件版本、UART 交叉、3.3V 供电
            └─ server=1 → 看 tcp= 字段
                           ├─ tcp=0 → 手机没连上 → 查 Wi-Fi、IP、端口
                           └─ tcp=1 → 查握手 → 查 seq、字段合法性、turn/servo 一致性
```

### 5.2 常见现象

| 现象 | 排查方向 |
| --- | --- |
| **AP 能加入，但网页/TCP 打不开** | **查 `CFG_ESP_WIFI_MODE` 是否为 2**（纯 AP）；查 `server=` 是否为 1 |
| 串口完全没有输出 | 供电、时钟配置、烧录是否成功 |
| `server=0` | ESP AT 固件版本不符、`PA2/PA3` 未交叉、ESP 供电不足（**ESP 峰值电流可达数百 mA**） |
| 姿态显示 `R:--- P:--- Y:---` | 看 USART3 的 `I2CBUS` → `IMUSCAN` → `IMU scl= sda= st= probe=` 三段诊断 |
| | `probe=` 无响应 → 多为 **`PB6/PB7` 缺 4.7 kΩ 外部上拉** |
| App 连上就断、反复重连 | **`AT+CIPSTO=3` + 固件只接受单个控制客户端**；**已知未修复项** |
| 收到 `E_RX_OVERFLOW` | UART 环形缓冲溢出，固件已丢弃残帧并停机；**必须收到一帧完整合法 CMD 才能重新建链** |
| 收到 `E_SEQ_OLD` / `E_SEQ_AMBIGUOUS` | 序号回绕问题；失联或溢出后序号窗口会清除，用新序号重发 |
| 电机无响应但 ACK 正常 | 查 `CFG_MOTOR_A_ENABLED` / `CFG_MOTOR_B_ENABLED` 是否为 1；查 `err` 位图 |

### 5.3 故障位图解读

`STA.err` 是**活动故障位图**的十进制值，可多故障叠加：

| 位 | 值 | 含义 |
| ---: | ---: | --- |
| 0 | 1 | 链路超时强制断链 |
| 1 | 2 | ESP/USART2 接收缓冲溢出或 ORE |
| 2 | 4 | IMU 数据过期 |
| 3 | 8 | IMU 软件 I²C 恢复失败 |
| 4 | 16 | 该路电机被配置禁用 |
| 5 | 32 | UART 发送队列丢弃 |
| 7 | 128 | OLED 软件 I²C 异常 |
| 8 | 256 | 关键配置与定时器初始化不一致 |

**例**：`err=5` 表示链路超时（1）+ IMU 数据超时（4）**同时存在**。

> 📌 协议错误用即时 `ERR` 帧告知；`STA.err` 只描述**持续活动的运行期故障**，两者不可混用。

---

## 六、安全策略（必读）

### 6.1 失联保护

超过 **1000 ms** 未收到有效命令时：

1. **两路电机停止**，A/B 两桥均进入 coast，不保持未知电流；
2. 舵机回中位（由 `CFG_SERVO_CENTER_ON_LINK_TIMEOUT` 控制，默认回中）；
3. `link=0`，置链路超时故障位，主动关闭旧 TCP 连接释放槽位。

> ⚠️ **失联停机不可关闭。** 本交付不提供关闭该项的开关。

### 6.2 溢出的处理更严格

ESP 接收缓冲溢出或 UART ORE 时：**立即丢弃残帧、重置解析器、清除会话与序号窗口、停止两路电机、舵机回中**，不等待普通的 1 秒保活超时。

之后必须收到一帧**完整且通过全部校验**的 `CMD` 才能重新建链。

### 6.3 一个重要设计原则

> **任何解析、语义或序号失败，都不能造成部分电机或舵机动作。**

协议栈在校验全部通过前不触碰执行器。复刻或改造时请保持这个原则 —— 宁可不动，不可动一半。

---

## 下一步

链路跑通、能稳定握手后，进入 [③ 电控编写](电控编写.md)。

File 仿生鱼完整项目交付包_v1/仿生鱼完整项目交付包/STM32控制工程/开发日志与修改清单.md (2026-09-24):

# STM32 控制工程 — 开发日志与修改清单

> **文档版本**：v3.2（合并版）
> **生成时间**：**2026-09-23**（最近一轮见 **附录 I**）
> **记录区间**：2026-09-08 ~ 2026-09-23
> **仓库基线**：分支 `main`，HEAD `a070a26`（"docs(v0.5): 清除源码注释里的步进口径与过时挡位描述"）
> **工作区状态**：**有未提交改动**（`bsp/Src/esp_link.c`）；`build-*` 构建目录不入库
> **合并来源**：本文档取代原 `交接说明_2026-09-10.md`（已删除），并完整保留其全部内容（见 §4、§9、附录 A/B）

---

## 0. 阅读指引

| 你想知道 | 看哪节 |
| --- | --- |
| 现在到底能不能用 | §1 一句话现状 |
| 板子上跑的是哪份固件 | §2 固件与产物 |
| 每个模块改了什么 | §3 修改清单（按轮次） |
| 2026-09-10 那轮的完整背景与硬件事实 | §4 历史轮次档案（原交接说明） |
| 还没解决的问题 | §5 遗留问题 |
| 踩过的坑 | §6 陷阱 |
| 怎么编译/烧录/抓串口 | §7 操作手册 |
| 串口输出怎么读 | §8 调试口速查 |

---

## 1. 一句话现状

| 子系统 | 状态 | 说明 |
| --- | --- | --- |
| 编译 / 宿主机测试 | ✅ 正常 | 固件 `-Werror` 交叉编译通过（v0.5 产物见 §G.4），**16/16** 宿主机测试通过（本机 GCC 15.2 下需 `-Wno-error=format-truncation`，见 §6-3） |
| **JY901S 姿态读取** | ✅ **已通** | 靠台架兼容开关走 STM32 内部上拉，实机读到真实角度（`e=0`、`R/P/Y` 实时变化） |
| **OLED 屏幕** | ⚠️ **时好时坏（硬件接触不良）** | 2026-09-11 复测：**同一固件同一接线，复位前 `err=1`（屏起来了）、复位后 `err=163`** ⇒ 虚接，非固件问题。故障点已从 PB8 变为 **PB9**，见 §5.1 |
| ESP-01S AT / TCP 服务 | ✅ 正常 | `server=1 tcp=0 reset=0 error=OK`，等客户端接入；`uloss` 稳态冻结 |
| **安卓 App 握手** | ❌ **未解决** | 固件侧已被现场证据证明正确，瓶颈定位到 App/下行时序，见 §5.2。需重编 APK |
| **双路直流电机 + 网页控制** | ⚠️ **代码完成、实板待验** | v0.5 起：TIM2 2 s 慢周期，满速挡 95% / 低速挡 60%，网页端双电机各三键；**实板带载驱动待验证**，见 §G.6 |
| **调试模式（板载按键）** | ✅ 已实现 | K1 启停 M1、K2/K3 舵机 ±15°，见 §3.6。**实际按键动作待人工验证；无 M2 按键** |
| 步进 / 舵机（协议路径） | 未验证 | 无反馈环节，`step_on` 只反映命令状态 |

---

## 2. 固件与产物

### 2.1 当前已烧录固件（2026-09-11）

```text
文件      : build-firmware/bionic_fish.bin
字节      : 26,656
SHA-256   : 2d80819670944055f60ec47cbe4d0300730af0894ad1074545ab6aaff9825936
Flash     : 40.67% (26,656 / 65,536)
RAM       : 7,904 / 20,480 (38.59%，含堆栈预留)
工具链    : arm-none-eabi-gcc 13.3.1 (STM32CubeIDE 1.19.0 内置)
CMake     : 4.2.2   |   STM32CubeF1: V1.8.6
源提交    : 9b97230，source_dirty = true
```

**烧录后已回读校验**：芯片 Flash 前 26,656 字节 SHA-256 与本地 bin **逐字节一致**，其后为 `0xFF`（已擦除）。也就是说，下列任何分析结论都直接对应板上运行的代码。

### 2.2 历史产物对照

| 时间 | 字节 | SHA-256（完整） | 说明 |
| --- | --- | --- | --- |
| 2026-09-10 22:36 | 26,044 | `63f8349fe5ca84fd55f20890aeccda8fa71516ac386e9d8627d24ab90a5a7ce2` | 原交接说明记录的版本（诊断版，无调试按键） |
| 2026-09-11 00:0x | 26,232 | `da66a367b00d74e43adf01636b410e4524085b513bedbe7acca434042e0e4b20` | 加入 CIPSEND 计数器（`etx/stx/sf/st`） |
| **2026-09-11 00:43** | **26,656** | **`2d80819670944055f60ec47cbe4d0300730af0894ad1074545ab6aaff9825936`** | **当前版本：+ 调试按键 + OLED 去 Astra** |

---

## 3. 修改清单（按轮次）

### 3.1 轮次 A — 2026-09-10：诊断能力建设与软 I²C 缺陷修复

> 原始记录见 §4。以下为摘要。

| 文件 | 改动 |
| --- | --- |
| `drivers/Src/soft_i2c.c` | ① **修缺陷**：`Stop()`/`WriteByte()`/`ReadByte()`/`BusRecover()` 在 `ClockHigh` 超时提前返回时，会把 SDA（ACK 分支）或 SCL 留在**主机自己拉低**的状态，把瞬时毛刺放大成永久死总线。新增 `ReleaseBothLines()`，所有错误路径统一释放，`FinishWithRecovery` 另加兜底。<br>② 新增只读诊断 `SoftI2c_LinesReleased` / `SoftI2c_LineLevels` / `SoftI2c_StatusName` / `SoftI2c_IdleLevelsWithInternalPullup`。<br>③ 新增台架兼容模式 `SoftI2c_SetInternalPullup()`：释放时切 `GPIO_MODE_INPUT+GPIO_PULLUP`，拉低时切回 `GPIO_MODE_OUTPUT_OD`。 |
| `drivers/Inc/soft_i2c.h` | 上述 API 声明；`SoftI2cBus` 增加 `bool internal_pullup` |
| `drivers/Src/jy61p.c` / `jy61p.h` | 只加诊断字段：`last_status` / `last_raw[6]` / `last_read_ok` / `attempts` / `errors`。**协议逻辑一行未改** |
| `app/Inc/app_config.h` | 新增 `CFG_IMU_DIAG_PERIOD_MS`（默认 1000，0 关闭）、`CFG_JY61P_INTERNAL_PULLUP`（**默认 1**，含 `>1` 的 `#error` 校验） |
| `app/Src/app.c` | 新增 `ServiceImuDiagnostics()`（1 Hz）、`ServiceImuScan()`（JY61P 总线独立扫描，未找到每 2 s 重来一轮）、上电一次 `I2CBUS` 空闲电平打印；`ServiceLinkDiagnostics` 扩展出 `id/ev/uloss/cmd` |
| `bsp/Src/bsp_uart.c` / `bsp_uart.h` | 新增累计计数器 `s_esp_rx_loss_count` 与 `BSP_Uart_EspRxLossCount()`（区别于会被消费清零的 `BSP_Uart_EspRxLost()`） |
| `bsp/Src/esp_link.c` / `esp_link.h` | 新增只读快照 `EspLink_ClientId()` / `EspLink_PendingEvents()` |
| `tests/host/Src/app_host_test.c` | 为新增诊断函数补桩 |
| 文档 | `硬件引脚与驱动说明.md` 新增诊断判据表；`README.md` 补充故障排查段 |

**已回滚**：曾把 `CFG_LINK_TIMEOUT_MS` 从 1000 改到 10000 以放宽 App 握手窗口，用户要求回滚，**已全部撤销**（`通信协议.md` 与 `protocol_host_test.c` 已确认回到 HEAD 状态）。

### 3.2 轮次 B — 2026-09-11：CIPSEND 下行事务计数器

**动机**：把"ACK 下行"与"STA 下行"分开定性，回答一个此前无法回答的问题 —— *ESP 到底有没有接受并发出那条 STA？*

| 文件 | 改动 |
| --- | --- |
| `bsp/Inc/esp_link.h` | 新增 `EspLinkSendCounters` 结构体与 `EspLink_GetSendCounters()` |
| `bsp/Src/esp_link.c` | 新增计数：`event_try/ok`（ACK/ERR）、`status_try/ok`（周期 STA）、`send_fail`（ESP 明确回 `ERROR`/`FAIL`/`SEND FAIL`/`link is not valid`）、`send_timeout`；新增 `L.cipsend_status` 标记在途 CIPSEND 承载的是哪一类帧 |
| `app/Src/app.c` | 诊断行扩展 `etx=ok/try stx=ok/try sf= st=`（`line[160]` → `line[224]`） |
| `tests/host/Src/app_host_test.c` | 补 `EspLink_GetSendCounters` 桩 |

**判据**：

- `stx` 的 ok 与 try **同步增长** ⇒ ESP 已回 `SEND OK`，STA 确实发出去了，丢失在 ESP 之后；
- try 涨而 **ok 不涨** ⇒ ESP 拒收或该次发送失败（固件/ESP 侧）；
- `stx` **完全不涨** ⇒ 固件从未尝试下发 STA（链路状态机问题）。

### 3.3 轮次 C — 2026-09-11：安卓 App 握手保活（App 侧）

**文件**：`仿生鱼安卓AP直连_v0.3.0_2026-09-06/Android工程/app/src/main/java/com/bionicfish/controller/device/DefaultBionicFishRepository.kt`（**本次唯一改动的 App 文件**，+65 / −? ）

| 改动 | 说明 |
| --- | --- |
| 新增字段 `handshakeKeepaliveJob: Job?` | — |
| `performV1Handshake()` | 在 `handshakeProbe = probe` 之后、`queueAndAwait()` **之前**启动续命；`finally` 中 `stopHandshakeKeepalive()`，覆盖 ACK 等待段（最长 900 ms）与一切异常路径 |
| 新增 `startHandshakeKeepalive()` / `stopHandshakeKeepalive()` | 每 `HANDSHAKE_KEEPALIVE_PERIOD_MILLIS = 400 ms` 复用**同一条命令、同一个 seq** 入紧急队列 |
| 新增常量 | `HANDSHAKE_KEEPALIVE_PERIOD_MILLIS = 400L` |

**为什么必须复用同一 seq**：固件 `Control_AcceptDuplicate` 对"同 seq 同载荷"只刷新 `link_alive` / `last_valid_command_ms`，**不推进 `last_sequence`**，因此 STA 的 `seq` 始终等于握手 `seq`，探针的同序号匹配不被打断。**若另发新 seq，STA 的 seq 会前移，探针将永远匹配不上。** 续命帧也不注册 ACK 等待器（`queueAndAwait` 已注册，重复会触发其内部 `check`）。

**不影响正常路径**：握手健康时 < 400 ms 完成，`finally` 先取消 job，续命帧一帧都不发；因此现有单测（`handshakeTimeoutMillis=100L` 两例、`MockTransport(0L)` 零延迟例）断言不受影响。

> ⚠️ **当前未生效**：交付包 APK 为 **0.3.0**，而源码是 **versionCode 5 / versionName 0.3.2**；本机无 Android SDK/Gradle 缓存，**APK 必须在构建机重编**。0.3.0 里连"本地通信日志"都没有。

### 3.4 轮次 D — 2026-09-11：OLED 去掉 ASTRA 静态标题

`ui/Src/oled_ui.c`：删除 `y=56` 行的 `Ssd1306_DrawString(display, 0U, 56U, "ASTRA STATIC UI")`。该行不携带任何状态信息，却占掉最后一行 8 px 字体空间（并额外占用约 150 字节 Flash）。

**当前布局**：仅使用 `y = 0 / 10 / 20 / 32 / 44` 五行，`y=56` 空出备用。已验证 `ASTRA` 不再出现在二进制中。

### 3.5 轮次 E — 2026-09-11：步进电机本地控制 API

| 文件 | 改动 |
| --- | --- |
| `control/Inc/motor_control.h` | 新增 `Motor_SetRunning(MotorController *motor, bool run, uint32_t now_us)` |
| `control/Src/motor_control.c` | 实现：不经过协议命令直接启停，同样遵守 `CFG_STEPPER_DRIVER_ENABLED`，只按单向（`step_reverse=false`）连续换相，**绝不产生反转**；仅从静止启动时重排换相时钟，已在转时不打断当前相位驻留 |

### 3.6 轮次 F — 2026-09-11：调试模式（板载按键映射）

**动机**：上位机（App/TCP）暂不可用时，仍能在台架上直接验证执行器。

| 文件 | 改动 |
| --- | --- |
| `app/Inc/app_config.h` | 新增 `CFG_DEBUG_BUTTONS_ENABLED`（**默认 1**），并纳入"布尔配置开关只能为 0 或 1"的 `#error` 校验 |
| `app/Src/app.c` | 新增 `DebugButton` 结构 + `ButtonPressEdge()`（按下沿 + 去抖）、`NoteDebugAction()`、`DebugButtonsInit()`、`ServiceDebugButtons()`；`CFG_DEBUG_BUTTONS_ENABLED=0` 时提供空实现；`App_Init()` 调用 `DebugButtonsInit()`；`App_Process()` 在链路超时处理**之后**调用 `ServiceDebugButtons()` |
| `tests/host/Src/app_host_test.c` | 新增 `button_levels[3]` 与 `BSP_ButtonPressed()` 桩；新增 `PressKey()`/`ReleaseKey()` 辅助与 `TestDebugButtons()`、`TestDebugMotionYieldsToHost()` |
| `硬件引脚与驱动说明.md` | 引脚表更新 + 新增 **§2.1 调试模式：板载按键映射** |
| `README.md` | 故障排查段新增调试模式条目 |

**按键映射**：

| 按键 | 引脚 | 动作 |
| --- | --- | --- |
| `K1` | PB0 | 切换步进驱动：按一次开始转，**再按一次停止** |
| `K2` | PB1 | 舵机左转 `CFG_SERVO_SAFE_MIN_DEG`（−30°，脉宽 1000 µs） |
| `K3` | PA8 | 舵机右转 `CFG_SERVO_SAFE_MAX_DEG`（+30°，脉宽 2000 µs） |

**实现要点**：

1. 三键低电平有效、内部上拉，按**按下沿**触发一次动作；去抖窗口 `CFG_BUTTON_DEBOUNCE_MS`（30 ms），窗口内抖动只算一次。
2. `DebugButtonsInit()` 以**真实电平**为初值 ⇒ 上电时已按住的键不会被当成一次"按下"。
3. 每次动作向 USART3 打一行 `DEBUG K1 stepper ON` / `DEBUG K1 stepper OFF` / `DEBUG K2 servo LEFT` / `DEBUG K3 servo RIGHT`。
4. 本地动作走 `Motor_SetRunning()`，**不经过协议**，不占序号窗口、不伪造远端命令。
5. **上位机始终优先**：任何被接受的远端 `CMD` 都立刻覆盖本地动作（`ApplyAcceptedCommand` 原逻辑未动）。
6. 按键服务置于 `Control_CheckTimeout()` **之后**，避免本轮按键被同一轮失效保护立刻撤销。

> ⚠️ **安全语义变化（必须知情）**：本功能有意放开"无链路即无运动"这条看门狗保证。`Control_CheckTimeout()` 只在 `link_alive == true`（曾经有过被接受的命令）时才可能触发，因此**纯本地调试时没有任何看门狗兜底** —— K1 启动的转动会一直持续到再按一次 K1。**下水前必须把 `CFG_DEBUG_BUTTONS_ENABLED` 设回 `0`。**

### 3.7 变更清单汇总（相对 HEAD `9b97230`，17 个文件）

```text
 M README.md
 M app/Inc/app_config.h
 M app/Src/app.c
 M bsp/Inc/bsp_uart.h
 M bsp/Inc/esp_link.h
 M bsp/Src/bsp_uart.c
 M bsp/Src/esp_link.c
 M control/Inc/motor_control.h
 M control/Src/motor_control.c
 M drivers/Inc/jy61p.h
 M drivers/Inc/soft_i2c.h
 M drivers/Src/jy61p.c
 M drivers/Src/soft_i2c.c
 M tests/host/Src/app_host_test.c
 M ui/Src/oled_ui.c
 M 硬件引脚与驱动说明.md
 M ../仿生鱼安卓AP直连_v0.3.0_2026-09-06/Android工程/app/src/main/java/com/bionicfish/controller/device/DefaultBionicFishRepository.kt
?? 代码审查问题清单_2026-09-08.md        （就在本目录，非本次产生，未纳入版本控制）
```

`通信协议.md` 与 `tests/host/Src/protocol_host_test.c` **不在列表中** —— 它们已完全回到 HEAD 状态（回滚那轮改动时确认过，见 §3.1）。

---

## 4. 历史轮次档案：2026-09-10 原始交接说明（完整保留）

> 以下内容原样保留自 `交接说明_2026-09-10.md`。其中部分结论已在 2026-09-11 被更新，**冲突处以 §5 为准**。

### 4.1 硬件事实（这一轮才确认的，非常重要）

1. **实物陀螺仪是 JY901S，不是文件/宏名里的 JY61P。**
   两者 I²C 协议**完全相同**（7 位地址 `0x50`、寄存器 `0x3D/0x3E/0x3F`、int16 小端、从 `0x3D` 连读 6 字节），维特智能官方 IIC 例程对 JY61P/JY901/JY901S/JY901B 标注为同一套用法。
   **因此 `jy61p.c` 未做任何协议改动**，`CFG_JY61P_*` 宏名也刻意保留未改名，避免改动面扩散。差异只在语义：JY901S 是 9 轴，`yaw` 是磁力计绝对航向（JY61P 只是陀螺积分会漂移）。

2. **PB6/PB7（JY901S 总线）没有外部上拉电阻。**
   STM32F1 的开漏输出模式忽略 PU/PD 位，"开漏 + 内部上拉"不可兼得，所以缺上拉时主机把线驱动为低之后，线靠引脚电容"记住"低电平，此后每次事务必然失败。

3. **PB8（OLED SCL）曾被判定为外部拉低** —— 详见 §4.2。**2026-09-11 更新：该结论已过期，故障点变为 PB9，见 §5.1。**

### 4.2 当时记录的 OLED 黑屏分析（非固件）

**证据**（当时开机抓包）：

```text
I2CBUS oled scl=0 sda=1 imu scl=1 sda=1 ipu=1
I2CSCAN none          ← OLED 总线 0x08..0x77 全无应答
IMUSCAN 0x50          ← JY901S 那条总线完全正常
err=163               ← 163 = 128(BF_FAULT_OLED_I2C) + 32 + 2 + 1
```

**当时推理**：`I2CBUS` 这行是在 `SoftI2c_Init()` 已对两条线写过 1（开漏释放）之后才读的，此时主机没驱动 PB8，它却读回 0；而 SDA 正常为 1 ⇒ 判定 PB8 被外部拉到地。回滚 `CFG_LINK_TIMEOUT_MS` 后 `err` 仍为 163，排除了上一轮改动。

**待办（当时）**：PB8↔OLED SCL 是否短路到 GND / 插针弯折搭脚；OLED 模块 VCC 对 STM32 GND 是否为 3.3 V；换线换针位。

### 4.3 `CFG_JY61P_INTERNAL_PULLUP=1` 是台架权宜，不是正解

当前默认 **1**，实测能跑通（`st=OK probe=1 fail=0 e=0`）。但：

- 内部上拉仅约 **40 kΩ**，边沿上升约 3 µs 量级，**抗 EMI 远弱于 4.7 kΩ**；
- 每个边沿多一次引脚模式写入，总线变慢；
- 维特智能本身要求 I²C 走线 10 cm 以内，兼容模式下这条约束更严。

**正确做法**：在 PB6、PB7 各加一只 4.7 kΩ 到 3.3 V，然后把 `CFG_JY61P_INTERNAL_PULLUP` 改回 `0`。**下水前必须完成这一步。** 该开关只作用于 JY61P 总线，OLED 总线（PB8/PB9）始终走标准开漏。

### 4.4 当时记录的调试口输出（正常态）

```text
I2CBUS oled scl=1 sda=1 imu scl=1 sda=1 ipu=1        ← 上电一次
I2CSCAN 0x3C                                          ← OLED 总线扫描（分步）
IMUSCAN 0x50                                          ← JY901S 总线扫描（分步）
IMU scl=1 sda=1 pu=-- st=OK probe=1 fail=0 n=240 e=0 raw=61034FFF361A R=4.7 P=-0.9 Y=36.8
ESP server=1 tcp=0 id=-1 reset=0 ev=0 uloss=324 cmd=0 error=OK
<STA,seq=0,link=0,step_rpm=NA,...,roll=4.7,pitch=-0.9,yaw=36.8,err=163>
```

**`err` 位图**（`control/Inc/faults.h`）：
`1`=链路超时、`2`=ESP 收字节丢失、`4`=IMU 数据超时、`8`=IMU 总线恢复失败、`16`=步进被禁用、`32`=UART 发送丢帧、`128`=OLED I²C。
OLED 屏上 `E:` 是低 12 位**十六进制**，串口 `err=` 是**十进制**，别混。

**`raw` 解码自检（2026-09-11 勘误）**：原记录写 `0xFF4F=-177 → -9.7 ddeg ≈ -1.0°`，**算错**。按 `jy61p.c:15` 的 `raw*1800/32768`（向零截断）：`-177*1800/32768 = -318600/32768 = -9` ddeg = **-0.9°**，与同段打印的 `P=-0.9` 一致。其余两项正确：`0x0361=865 → 865*1800/32768 = 47 ddeg = 4.7°`；`0x1A36=6710 → 368.6 ddeg = 36.8°`。

**PC13 判据**：OLED 初始化失败时快闪（120 ms），成功时慢闪（500 ms）。

### 4.5 当时记录的 `CFG_LINK_TIMEOUT_MS` 取舍说明

`CFG_LINK_TIMEOUT_MS=1000` 与 App 的 2000 ms 握手窗口相比偏紧，这是**被回滚掉的改动原本要解决的问题**（当时未意识到它其实是结构性竞态，见 §5.2）。

### 4.6 ESP 服务端固定 `CIPSTO=3` 的边界（原交接说明所属的链路设计）

- 服务端固定 `AT+CIPSTO=3`（3 秒），正常 500 ms 保活不会触发它。ESP8266 ESP-AT 2.2 官方明确**服务端单向发送不重置此计时**；NONOS 文档支持同一命令，但未明确陈述双向计时细节，因此代码**不依赖该细节**完成应用保护。
- 已经建立的有效 CMD 会话超过 1000 ms 时，应用还调用 `EspLink_CloseClient()`，立即隔离旧字节、并在当前发送事务安全终结后对原 ID 发 `AT+CIPCLOSE`，释放唯一的客户端槽位；**初次 TCP 握手前不会触发这一应用计时**。
- 这样无效流量或单向 STA 就不能让失效的控制会话一直占住唯一槽位 —— 但**它也正是 §5.2 那个 1 秒竞态的来源**：握手期间只有一条被接受的命令，1 秒后 TCP 就被主动关闭。
- CIPSEND 采用"先发头 → 收到 `>` 才发精确载荷 → 收到 `SEND OK` 才发下一事务"，不额外添加 CRLF、不使用固定冷却限制吞吐。
- **不能证明 ESP 已退出 CIPSEND 数据阶段时，禁止盲发 `AT+RST` 或 `+++`。** 700 ms 发送超时先使应用断链停机；随后最多等 5 秒获取迟到的提示/终结响应。迟到 `>` 可用等长空格加 LF 完成本次已声明的载荷，再在终结响应后复位；若无终结证据，`EspLink_ResetNeeded()` 锁存为真。该板**未提供 ESP 硬件复位控制脚**，软件无法承诺这类故障自动恢复。

### 4.7 原交接说明记录的"未提交改动清单"

相对 HEAD `9b97230`（**这是 2026-09-10 的状态，当前状态见 §3.7**）：

```text
 M README.md
 M app/Inc/app_config.h
 M app/Src/app.c
 M bsp/Inc/bsp_uart.h
 M bsp/Inc/esp_link.h
 M bsp/Src/bsp_uart.c
 M bsp/Src/esp_link.c
 M drivers/Inc/jy61p.h
 M drivers/Inc/soft_i2c.h
 M drivers/Src/jy61p.c
 M drivers/Src/soft_i2c.c
 M tests/host/Src/app_host_test.c
 M 硬件引脚与驱动说明.md
?? 代码审查问题清单_2026-09-08.md        （就在本目录，非本次产生）
```

### 4.8 原交接说明记录的串口抓包配方

**要抓开机那几行**（`I2CBUS` / `I2CSCAN` / `IMUSCAN`）时，必须让抓包先跑起来再复位：

```bash
powershell.exe -NoProfile -ExecutionPolicy Bypass -File scripts/read_com7.ps1 -Port COM7 -Secs 16 > /tmp/x.txt 2>&1 &
sleep 3
"D:/STM32CubeProgrammer/bin/STM32_Programmer_CLI.exe" -c port=SWD mode=NORMAL freq=4000 reset=SWrst \
  -w build-firmware/bionic_fish.bin 0x08000000 -v -rst
wait
grep -E "^I2CBUS|^I2CSCAN|^IMUSCAN|^ESP " /tmp/x.txt
```

> **USART3 是只发不收的**（`bsp_uart.c` 里只有 `huart2` 挂了 `HAL_UART_Receive_IT`），
> 所以**没法从 COM7 灌控制命令**；命令只能走 ESP 的 TCP。

---

## 5. 遗留问题（2026-09-11 最新结论）

### 5.1 OLED：从"被拉死"改判为"接触不良"，故障点由 PB8 变为 PB9

**2026-09-11 现场证据**：

| 时刻 | `I2CBUS` 行 | `err` | 含义 |
| --- | --- | --- | --- |
| 复位**前**（已运行约 7 分钟，`n=8681`） | — | **1** | bit 128 为 0 ⇒ **OLED 初始化成功过**，屏是亮的 |
| 复位**后**（开机首行） | `oled scl=1 sda=0` | **163** | bit 128 置位；`I2CSCAN none` |

**结论**：**同一块固件、同一套接线，时好时坏 ⇒ 虚接/松动，不是被硬拉死。** 而且故障点从原来的 `scl=0 sda=1` **反成了 `scl=1 sda=0`** —— 现在该查的是 **PB9 ↔ OLED SDA**（排针、杜邦线、焊点），而不是 PB8。

**下一步**：重点检查 PB9 那根线的接触；换线换针位；确认 OLED 模块 VCC 对 STM32 GND 为 3.3 V。

### 5.2 安卓 App 握手失败：固件侧已证清白，瓶颈在 App/下行时序

**现象**：App「设备」页报 *"TCP 已连接，但 STM32 未完成 ACK + STA 验证；握手超时：未在 2000 ms 内同时收到 ACK 与有效 STA"*（用户 2026-09-11 确认）。

**2026-09-11 抓到的完整现场**（6 次连接尝试，形态完全一致）：

```text
ESP server=1 tcp=1 id=0 reset=0 ev=0 uloss=331 cmd=0 error=OK
<ACK,seq=11,result=OK>
<STA,seq=11,link=1,step_rpm=NA,...,err=160>      ×5
ESP server=1 tcp=0 id=-1 reset=0 ev=2 uloss=331 cmd=1 error=Command heartbeat expired; closing TCP
```
随后 seq=12,13,14,15,16,17 重复同样形态。

**关键推断（已收窄）**：

1. **ACK 必然到达了手机。** App 侧 `commandAckTimeoutMillis` 默认 800 ms，且被 `MAX_COMMAND_ACK_TIMEOUT_MILLIS = 900`（`AppSettings.kt:103`）**硬性封顶**，同时强制 `< linkTimeoutMillis`。而报错是 **2000 ms 的握手超时**，不是 800 ms 的 ACK 超时 ⇒ ACK 在那之前就完成了匹配。
2. **固件下行两个条件都满足。** ACK 与 **同 `seq`、`link=1`** 的 STA 都发出了（1 秒内 5 次）。`app_host_test.c` 用 App 那条**一模一样**的帧 `<CMD,seq=0,move=S,turn=C,step_speed=60,servo=0>` 也断言过 200 ms 内出现 `<STA,seq=0,link=1,…>`；`esp_link_host_test` 断言客户端收到 `<ACK,seq=1,result=OK>`。
3. **`ev=2` 不是新故障。** `esp_link.h:13` 定义 `ESP_LINK_EVENT_DISCONNECTED = 1<<1 = 2`，它就是固件自己 `EspLink_CloseClient()` 里 `Invalidate(...)` 置的位，属**自伤**；全程无 `AT send failed`，`ev` 从未出现 bit 4。
4. **结构性竞态**：固件 `CFG_LINK_TIMEOUT_MS=1000` 在最后一条被接受的命令后约 1 秒关闭 TCP；而 App 握手窗口 2000 ms，且 `startPeriodicControl()` 要等握手通过才启动 ⇒ **整个握手期间只有那一条 STOP 在续命**。任何延迟都会让固件先关连接，App 取不到有效 STA、重连、seq+1、再被同样关掉，形成死循环 —— 与观察到的 6 次整齐重复吻合。这说明**当初把 `CFG_LINK_TIMEOUT_MS` 放宽到 10000 的改动方向是对的**（见 §3.1 已回滚）。
5. **App 侧解析逻辑已逐条排除**：ACK 匹配键 `Outbound.sequence = command.sequence` 正确；接收协程用 `CoroutineStart.UNDISPATCHED` 在 `connect()` **之前**启动，HANDSHAKING 期间照收；分帧器正确剥掉 `<`/`>`（故 `err=160` 不会解析失败）；`telemetryTracker.accept()` 是纯映射、不抛异常、不挡 `statusSeen`；`AsciiProtocol.kt:82` 只要求 `err >= 0`，所以 **`err` 非零不挡握手**（OLED 的 bit 128 不是原因）。

**当前已做的修复**：§3.3 的 App 保活。**但它只是必要条件，未必充分** —— 若那 5 条 STA 真的没到手机，加保活只能让 TCP 不被提前掐断，握手仍过不去。

**下一步（用 §3.2 的计数器一刀切开）**：让用户重跑一次连接，读 `ESP … stx=ok/try`：

| 现象 | 结论 | 方向 |
| --- | --- | --- |
| `stx` ok 与 try 同步增长 | ESP 已确认发出 STA | 丢失在 ESP 之后 ⇒ App/网络侧 |
| try 涨、ok 不涨 | ESP 拒收或发送失败 | 固件/ESP 侧真问题 |
| `stx` 完全不涨 | 固件从未尝试下发 STA | 链路状态机（`EspLink_SendStatus` 的 `IsClientConnected` 门控） |

**另一条无需 APK 的替代验证**：把 PC 连到 `BionicFish-AP`，用 TCP 客户端直接打握手帧并抓字节（需先让手机断开，因固件设了 `AT+CIPSERVERMAXCONN=1` 只允许一个客户端）。

### 5.3 已知代码问题（本机审查发现，均未修）

1. **`BF_FAULT_UART_TX_DROPPED`（bit 32）只置位、永不清除。** `app.c` 中 4 处置位（`Broadcast` / `ServiceStatus` ×2 / `ServiceLinkEvents`），**0 处 `ClearFault`**，而 `s_faults = 0U` 只在 `App_Init()` 执行一次。实机证据：复位后 750 条 STA 全部 `err=163`，30 秒内一直是 163。**后果**：一旦掉过一次，`err` 会锁存整个上电周期，OLED 修好后屏上 `E:` 仍非零，极易误导后续调试。
2. **`SoftI2c_LinesReleased()` 是死代码**：声明、实现、测试桩齐全，生产代码**一处未调用**（`soft_i2c.c:349` 是唯一引用）。
3. **`ServiceImuScan` 在传感器缺失时每 2 s 重扫 112 个地址**（0x08–0x77，5 ms 一个），与 JY901S 的 50 ms 采样**共用同一条总线、同一个 `consecutive_failures` 计数器**。线松时会互相干扰，并把"线的问题"混进 IMU 故障计数。建议收窄地址范围（或只探 0x50）。
4. **`CFG_JY61P_INTERNAL_PULLUP=1` 是台架权宜**（见 §4.3），下水前必须焊 4.7 kΩ 并改回 0。
5. **`CFG_DEBUG_BUTTONS_ENABLED=1` 放开了无链路看门狗**（见 §3.6），下水前必须改回 0。

### 5.4 其它参考

- `ESP01S_AP_UDP_Bridge/README.md` 描述的**无 AT 自定义透传桥**与当前固件（AT + TCP）**互斥**。按该目录刷 ESP 会让 `esp_link.c` 发的 `AT+…` 变成普通 UDP 数据、`+IPD` 永远等不到 ⇒ **请保持 ESP 出厂 AT 固件，勿刷本目录固件**。
- `代码审查问题清单_2026-09-08.md`（本目录，未纳入版本控制）：其中 **B-1 已过期**（断言 `BSP_Uart_EspRxLost()` 无调用方，实际 `esp_link.c:345` 的 `CheckUartLoss()` 正在调用），**B-2 也已过期**（`+IPD` 状态机在 HEAD 上已修好：`esp_link.c:294-298` 有位数/溢出/上限三重防护，`esp_link.c:416` 有 500 ms 字节间隔看门狗）。**引用该清单前先回读源码确认。**

---

## 6. 陷阱（踩过的坑，别重复）

1. **`git checkout -- <文件>` 会连前几轮要保留的改动一起清掉。**
   `app_config.h` / `app_host_test.c` 里同时压着多轮改动，回滚必须**按内容外科手术式编辑**，不能整文件 checkout。

2. **工具链不在 PATH 里。** 仓库自带 `scripts/build.py`，但 Windows 上需显式传路径，见 §7。

3. **宿主测试在 GCC 15.2 下会因一个既有告警失败。**
   `tests/esp_link/esp_link_host_test.c:104` 的 `snprintf("%s")` 触发 `-Wformat-truncation`，而 `CMakeLists.txt:18` 给宿主测试无条件加了 `-Werror`。**这是改动前就有的问题**（用 `git stash` 在干净树上复现过），交付文档写明本机基线是 MinGW-w64 GCC 8.1.0，那时不报。
   **推荐做法（2026-09-11 改用）**：直接在命令行加 `-Wno-error=format-truncation`，**不修改 `CMakeLists.txt`**，比原记录的"临时 sed + `git checkout`"安全得多。根治办法是修掉那行 `snprintf`。

4. **改 `CFG_LINK_TIMEOUT_MS` 会连带打挂两个宿主机测试。**
   `protocol_host_test.c:180` 用 `0x00000400`、`app_host_test.c` 用 `At(1099)/At(1100)`、`At(4401)/At(6200)/At(8200)` 把 1000 ms 写死在时间戳里。要改这个常量就得同步改这两处（且 `TestOledRecovery` 的时间戳还必须与 `CFG_OLED_RETRY_MS` 的节奏对齐，否则重试槽位会被吃掉）。

5. **ESP 上电时会有数十次 `E_RX_OVERFLOW` 刷屏**，之后 `uloss` 冻结不再增长。
   这是 ESP 启动时以 74880 波特率吐乱码、STM32 按 115200 收导致的溢出，属**启动瞬态**。实测记录：原文档写"约 39 次"，2026-09-11 实测 **36 次**，`uloss` 稳定在 **322~340** 后不再增长。

6. **`python` 在 PATH 上指向一个坏的 DevEco venv 启动器**（报 `No Python at 'D:\Python38\python.exe'`）。用 `D:/msys64/mingw64/bin/python3.exe`。

7. **`build-firmware/` 被 `.gitignore` 忽略**，重建不会污染仓库。

8. 用户给的截图路径可能是有嵌套的同名目录（例如 `D:/Huawei Share/Huawei Share/...`），找不到时搜文件名。

9. **在本机 DSH 沙箱里编译会挂**（2026-09-11 新增）：
   - ARM 交叉编译在受限沙箱中会**中途停住**（`cc1` 进程消失、`cmake`/`ninja` 停在 ~0 CPU），必须用 `sandbox_permissions: danger-full-access` 才能编完；
   - **构建命令不能接管道**：`… 2>&1 | Select-Object -Last 35` 会让整个构建挂住不动，去掉管道即可正常完成；
   - `Get-PnpDevice` 在本机返回 **0 个设备**（连 USB 根集线器都没有），**这不代表硬件没插** —— 串口要用 `[System.IO.Ports.SerialPort]::GetPortNames()` 或直接试开端口来判断；
   - .NET 静态方法与 `[System.IO.File]::ReadAllBytes()` **不接受相对路径**，必须给绝对路径。

---

## 7. 操作手册：构建 / 测试 / 烧录 / 抓串口

### 7.1 交叉编译固件

```powershell
cd "C:\Users\CloudyRain\Desktop\待办\仿生鱼工程\仿生鱼完整项目交付包_v0.3.1\仿生鱼完整项目交付包\STM32控制工程"
& "D:/msys64/mingw64/bin/python3.exe" scripts/build.py firmware `
  --cmake "D:/CLion 2026.1/bin/cmake/win/x64/bin/cmake.exe" `
  --ninja "D:/CLion 2026.1/bin/ninja/win/x64/ninja.exe" `
  --toolchain-bin "D:/STM32CubeIDE_1.19.0/STM32CubeIDE/plugins/com.st.stm32cube.ide.mcu.externaltools.gnu-tools-for-stm32.13.3.rel1.win32_1.0.0.202411081344/tools/bin" `
  --cube-path "C:/Users/CloudyRain/STM32Cube/Repository/STM32Cube_FW_F1_V1.8.6"
```

输出在 `build-firmware/`（elf / bin / map / `build-info.json`）。
> 用其它 CMake/编译器时换新的 `--build-dir`，别复用别套工具链的 CMake 缓存。**勿接管道**（见 §6-9）。

### 7.2 宿主机测试（17 个）

```powershell
cd "C:\Users\CloudyRain\Desktop\待办\仿生鱼工程\仿生鱼完整项目交付包_v0.3.1\仿生鱼完整项目交付包\STM32控制工程"
& "D:/msys64/mingw64/bin/python3.exe" scripts/build.py host --build-dir build-verify-host `
  --cmake "D:/CLion 2026.1/bin/cmake/win/x64/bin/cmake.exe" `
  --ninja "D:/CLion 2026.1/bin/ninja/win/x64/ninja.exe" `
  --host-cc "D:/msys64/mingw64/bin/gcc.exe"
```

> 若在 GCC 15.2 下因 `-Wformat-truncation` 失败，见 §6-3：**不要**改 `CMakeLists.txt`，改用命令行直编（10 个可执行 + 7 个 `config_*` 编译期检查 = 17 项）。

### 7.3 烧录

```powershell
& "D:/STM32CubeProgrammer/bin/STM32_Programmer_CLI.exe" `
  -c port=SWD mode=NORMAL freq=4000 reset=SWrst `
  -w build-firmware/bionic_fish.bin 0x08000000 -v -rst
```

ST-LINK 实测可用（SN `37FF71064E573436019F1143`，F103，3.31 V）。末尾 `-rst` 会做软件复位。

**校验烧录结果**（回读前 N 字节与本地 bin 比对 SHA-256，注意别把尾部已擦除的 `0xFF` 算进去）：

```powershell
$tmp="$env:TEMP\rb.bin"
& "D:/STM32CubeProgrammer/bin/STM32_Programmer_CLI.exe" -c port=SWD mode=NORMAL freq=4000 -u 0x08000000 0x8000 $tmp
```

### 7.4 抓 USART3（调试口，PB10/PB11 → CH340 → COM7）

```powershell
& powershell.exe -NoProfile -ExecutionPolicy Bypass -File scripts/read_com7.ps1 -Port COM7 -Secs 8
```

**要抓开机那几行**（`I2CBUS` / `I2CSCAN` / `IMUSCAN`）时，必须让抓包先跑起来再复位：先启动抓包（后台、写文件），等 3~4 秒，再执行 §7.3 的烧录或 `-rst` 复位。

> **USART3 是只发不收的**（`bsp_uart.c` 里只有 `huart2` 挂了 `HAL_UART_Receive_IT`），
> 所以**没法从 COM7 灌控制命令**；命令只能走 ESP 的 TCP。
> **一次只能有一个进程占用 COM7** —— 抓包没结束就再开一个会报 `Access to the port 'COM7' is denied`。先确认没有遗留抓包进程。

---

## 8. 调试口输出速查（2026-09-11 版）

```text
I2CBUS oled scl=1 sda=1 imu scl=1 sda=1 ipu=1        ← 上电一次
I2CSCAN 0x3C                                          ← OLED 总线扫描（分步）
IMUSCAN 0x50                                          ← JY901S 总线扫描（分步）
IMU scl=1 sda=1 pu=-- st=OK probe=1 fail=0 n=8681 e=0 raw=520358FF2724 R=4.6 P=-0.9 Y=50.8
ESP server=1 tcp=0 id=-1 reset=0 ev=0 uloss=331 cmd=0 etx=0/0 stx=0/0 sf=0 st=0 error=OK
DEBUG K1 stepper ON                                   ← 调试按键动作（新增）
<STA,seq=0,link=0,step_rpm=NA,step_est=NA,step_actual=NA,step_on=0,servo=0,roll=4.6,pitch=-0.9,yaw=50.8,err=163>
```

**字段含义**：

- `IMU …`：`scl/sda` 为软件 I²C 空闲电平；`pu` 仅在总线不空闲时做内部上拉探测（`pu=--` 表示总线空闲为高，属正常）；`st` 最近一次软 I²C 结果；`n` 累计采样尝试、`e` 累计 I²C 失败；`raw` 最近一次成功读取的 6 字节。
- `ESP …`：`server` AT 服务就绪、`tcp/id` 客户端槽位、`ev` 未消费事件位、`uloss` 累计 USART2 丢字节、`cmd` 已接受命令数、`error` 最近一次错误文案。
- `etx=ok/try` ACK/ERR 的 CIPSEND 事务、`stx=ok/try` 周期 STA 的 CIPSEND 事务、`sf` ESP 明确拒绝次数、`st` 超时次数（见 §3.2 判据）。
- **`err` 位图**见 §4.4。注意 **bit 32 会锁存**（见 §5.3-1）。

---

## 9. 建议的下一步优先级（2026-09-11 更新）

1. **人工验证调试按键**（§3.6）：按 K1 看起转/停止、K2/K3 看舵机左右 30°，同时观察 COM7 是否每次出一行 `DEBUG …`。若完全无反应，先看有无 `DEBUG` 行 —— 有行不动是执行器侧，无行多半是按键极性（把 `CFG_BUTTON_ACTIVE_LOW` 改 `0`）。
2. **重跑 App 连接并读 `stx`**（§5.2），据此判定 STA 下行到底断在哪一段。
3. **修 OLED 接触**（§5.1）：重点查 **PB9/SDA** 那根线。
4. **重编 Android APK**（源码 0.3.2 含保活修复与日志导出），并在构建机上跑 Kotlin 单测。
5. **修 §5.3 的已知代码问题**：bit 32 锁存（影响最大，会持续误导诊断）、`SoftI2c_LinesReleased` 死代码、IMU 全地址扫描。
6. **焊 PB6/PB7 的 4.7 kΩ 上拉**并把 `CFG_JY61P_INTERNAL_PULLUP` 改回 0（§4.3），下水前必办。
7. **下水前**把 `CFG_DEBUG_BUTTONS_ENABLED` 改回 0（§3.6）。
8. 决定 `CFG_LINK_TIMEOUT_MS` 取值 —— 需同时改两个宿主机测试的时间戳（§6-4）。
9. 根治 §6-3 的 `-Wformat-truncation`，别再用命令行绕过。

---

## 附录 A：仓库里已有的其它参考

- `README.md` —— 交付总览、运行与故障排查
- `通信协议.md` —— CMD/ACK/STA/ERR 帧格式与失联策略
- `硬件引脚与驱动说明.md` —— **引脚表 + 全部诊断判据 + §2.1 调试按键映射**
- `验收检查清单.md` —— 验收项
- `代码审查问题清单_2026-09-08.md` —— 2026-09-08 的静态审查，**其中 B-1、B-2 已过期**（见 §5.4），其余条目未逐条核对、一条都没修
- `scripts/BUILDING.md` —— 构建路径与依赖版本约定

## 附录 B：2026-09-11 本轮验证证据一览

| 验证项 | 方法 | 结果 |
| --- | --- | --- |
| 基线一致性 | `git status --porcelain` | HEAD `9b97230`，17 个改动文件与清单一致 |
| 回滚彻底性 | `git diff -- 通信协议.md tests/host/Src/protocol_host_test.c` | 空 ⇒ 已完全回到 HEAD |
| 固件可复现性 | 交叉编译 + SHA-256 比对 | 26,044 → 26,232 → 26,656 三次版本哈希均已核对 |
| 烧录正确性 | CubeProgrammer 回读 + SHA-256 | 与本地 bin **逐字节一致** |
| 宿主机测试 | 命令行直编 10 可执行 + 7 编译期检查 | **17 PASS / 0 FAIL** |
| `-Wformat-truncation` 根因 | GCC 15.2 复现 | 确认在 `esp_link_host_test.c:104`，仅测试文件，生产码干净 |
| OLED 时好时坏 | 复位前后对比同固件同接线 | `err=1` ↔ `err=163`，判定虚接 |
| `err` bit 32 锁存 | 150 s 抓包统计 | 750 条 STA 全为 `err=163` |
| `ev=2` 语义 | 源码对照 `esp_link.h:13` | = `ESP_LINK_EVENT_DISCONNECTED`，自伤非故障 |
| ASTRA 移除 | 二进制字符串搜索 | `ASTRA` 不存在；`DEBUG %s`/`K1 stepper`/`K2 servo` 存在 |
| 调试按键无自触发 | COM7 上电抓包 | 自发 `DEBUG` 行 **0** 条 ⇒ 无浮空误判 |

---

## 附录 C：2026-09-11 第二轮 —— App 根因定案 + 方案 B（网页控制）落地

> **§5.2 关于"1 秒竞态是主因"的推断已被推翻，以本节为准。**

### C.1 【定案】App 握手失败的真因：APK 落后两个提交

| 事实 | 证据 |
| --- | --- |
| 交付包 APK 构建于 **2026-09-06 17:44** | 文件 mtime；`AsciiProtocol.kt` 在此之后的 `1fe941d`(09-07)、`9b97230`(09-09) 被改过两次 |
| 该 APK 早于修复提交 | `git log -1 --until="2026-09-06 17:44"` = `99a5005` |
| **旧版把每一条 STA 都判为 Malformed** | 旧条件含 `stepTarget == null`；固件发 `step_rpm=NA` → 解析成 null → 整帧被丢弃 ⇒ **ACK 收得到、STA 永远验证不过 ⇒ 2000 ms 握手超时**，与截图报错一字不差 |
| 修复已在树里 | `(stepTarget == null && fields["step_rpm"] != "NA")` 两行；同提交含 `step_on` 处理、`versionCode 3→5`、`versionName 0.3.0→0.3.2` |

**结论：用树里的源码重编 APK 即可，协议与固件都不必改。** 本轮已把版本提升为 **0.4.0 / versionCode 6**，并产出交接文档 `桌面\仿生鱼APK重编说明_v0.4.0.md`。

### C.2 撤回上一轮的两个错误判断

| 曾写入 §5 的结论 | 实际 | 证据 |
| --- | --- | --- |
| "姿态角 74 s 冻结，疑似固件 bug" | ❌ **误判** | `raw=E20057FC2035→E20058FC2135` 每采样都在变、`e=0`；静止板 + 0.1° 量化下 roll/pitch 恒定、yaw 缓慢步进都正常 |
| "板上固件不是这份源码" | ❌ **错误** | 回读芯片 SHA-256 = 本地 bin，逐字节一致；`step_rpm=NA` 在、`step_rpm=%u` 不在 |

固件在实机上被完整洗清：同帧连发 → `OK` → `DUP` → `DUP`；同 seq 异载荷 → `E_SEQ_CONFLICT`。

### C.3 新增：ESP 双模 + 网页控制（方案 B）

**新增配置**（`app/Inc/app_config.h`）：`CFG_ESP_WIFI_MODE`（默认 3 = AP+STA）、`CFG_ESP_MAX_CLIENTS`（4）、`CFG_ESP_STA_SSID/PASSWORD`（明文，交付前应清空）。

| 文件 | 改动 |
| --- | --- |
| `bsp/Src/esp_link.c` / `esp_link.h` | `SET_MODE` 改用 `CFG_ESP_WIFI_MODE`；新增 `SET_CHECK_STA_IP` 步骤与 `ParseStaAddressLine()`；**空闲时补查 STA 地址**（配置阶段模块还没 `WIFI GOT IP`），新增 `AT_STA_IP` 事务；`CIPSERVERMAXCONN` 改用配置；新增 **`EspLink_SendRaw()`** 与 HTTP 专用发送槽 |
| `protocol/Src/http_ui.c` / `http_ui.h`（**新增**） | 纯逻辑 HTTP：请求行/头区状态机、`/`、`/api/status`、`/cmd?move=`、`/servo?deg=`、`/favicon.ico`、404；响应带 `Content-Length` + `Connection: close`；控制页为 Flash 常量 |
| `app/Src/app.c` | **首字节分流**（`'G'`→HTTP，其余→原协议，**共用 9000 端口**）；抽出 `RouteCommand()` 供远端 CMD 与网页端点共用；`BuildWebCommand()` 用 `last_sequence+1` 合成命令；HTTP 期间抑制周期 STA |
| `app/Inc/app_types.h` | `BfSystemSnapshot` 增加 `sta_ip[16]` |
| `ui/Src/oled_ui.c` | 释放出来的 `y=56` 行改显 `WEB <sta_ip>:9000`；`line[24]→[32]` |
| `CMakeLists.txt` | 固件与 app 宿主机测试加入 `protocol/Src/http_ui.c` |
| 测试 | 新增 `TestHttpWebControl`、`TestHttpSequenceWindow`（app_host_test）、`TestRawChunkedResponse`（esp_link_host_test）；假 ESP 载荷缓冲 200→600 |

**现场实测（PC 经校园网直连 `192.168.3.40:9000`）—— 11/11 通过：**

```
GET /                -> 200，页面含 /cmd?move=F 与 /servo?deg=-30
GET /cmd?move=F      -> move=F step=1 servo=0 link=1 err=0
GET /servo?deg=-30   -> servo=-30
GET /servo?deg=30    -> servo=30
GET /servo?deg=99    -> servo=30（夹紧）
GET /servo?deg=0     -> servo=0
GET /cmd?move=S      -> move=S step=0
GET /cmd?move=R      -> 被单向限制拒绝（step=0，link=0，err=1）
GET /favicon.ico     -> 204
GET /nope            -> 404
GET /api/status      -> sta=192.168.3.40  cmd=6
```

**两条路径共存验证（同一端口）**：协议客户端 `<CMD,seq=100,…>` → `<ACK,seq=100,result=OK>` + `<STA,seq=100,link=1,…>`；同 seq 重发 → `OK` 后 `DUP`；HTTP 与协议交替请求互不影响；最终 `<ACK,seq=101>` + `<STA,…,step_on=1>` 证明电机确实由协议命令驱动。

### C.4 第二轮踩到的两个真坑（都已修）

1. **单次 CIPSEND 载荷超过串口 TX 环（512 B）会永久卡死事务。**
   HTTP 响应约 810 B，一次性 `AT+CIPSEND=0,810` → `QueueRaw` 要求 `TxFree() >= 810`，**永远为假** → 卡在 `AT_BODY` → 700 ms 超时 → `abandon_send` → `NeedReset`。实机表现 `etx=0/1`、`reset=1`、`error=CIPSEND state unknown`。
   **修复**：按 `RAW_CHUNK_BYTES = 384` 分片，整段发完才清 `raw_pending`。
   ⚠️ 更严重的是它会把 **ESP 留在"等待 CIPSEND 载荷尾巴"的状态**，此时 ESP 吞掉一切输入（含 `AT`），而 ESP 的 EN/RST 没接 STM32 ⇒ **只能断电恢复**。本轮实际遇到一次。

2. **周期 STA 会污染浏览器响应。**
   浏览器连上后、发出请求前，固件会先推 `<STA,…>`；浏览器在 `HTTP/1.1` 之前读到非法数据即解析失败。
   **修复**：`ServiceStatus` 只在客户端**已分类为协议客户端**时才发 STA。副作用：HTTP 客户端不再产生 `stx` 计数（预期）；协议客户端仅损失连接后最初几十毫秒的 STA。

### C.5 第二轮新增的已知限制

1. **网页端受同一条 1 秒失联保护约束**：点一次 = 一条命令，1 秒内没有新请求就自动停机、舵机回中。要连续前进必须让页面轮询（**当前页面还没实现轮询，点一次只走一下**）。这是有意的安全语义，不是 bug。
2. **动作端点自回状态**：`/cmd` 与 `/servo` 的响应体带 `step=/servo=/link=/err=`，点完立刻能确认；否则 1 秒后失效保护已把状态改回去，用户会误以为没生效。
3. **校园网暴露面**：`CFG_ESP_WIFI_MODE=3` 时 `192.168.3.40:9000` 对同网段所有人开放，且协议与网页**都没有认证**。演示/比赛建议改回 `2`（纯 AP，有密码）。
4. **`CFG_ESP_STA_SSID/PASSWORD` 明文入库**，交付前应清空。
5. **STA 凭据依赖模块 flash 已保存**：固件尚未下发 `AT+CWJAP_CUR`（仍在待办），换模块/换网需先手动配一次。

### C.6 最终产物

```text
bionic_fish.bin  30,688 字节
SHA-256          48306f3d1c9c6d48184ad7e3e0e13e6876980695d2bc0d7affbbfe1fffebba43
Flash 46.83%    RAM 49.84% (10,208 / 20,480 B)
STM32 宿主机测试 17/17 通过
烧录后回读校验：与本地 bin 逐字节一致
```

---

## 附录 D：2026-09-11 第三轮 —— 网页端"完整控制能力"（连续驱动 + 转向）

> 目标：网页不只是"点一下走一下"，而要能真正把鱼开起来。**已达成并实测。**

### D.1 核心机制：页面自己轮询，而不是放宽看门狗

固件 1 秒失联保护是**安全设计**，不能为了网页方便就取消。正确解法是让页面按固件能接受的节奏续命：

- 控制页内嵌 JS，在"持续运行"期间**每 400 ms** 用 `fetch` 重发一次 `/cmd?move=..&servo=..`；
- 固件侧**一行都没为网页放宽**：停发 1.5 s 后仍会按失联保护自动停机（已实测，见 D.3 第 5 项）。

### D.2 本轮改动

| 项 | 内容 |
| --- | --- |
| **控制页重写** | 带 JS/CSS：前进（连续）/ 停止 / 左舵 / 直行 / 右舵 + 实时状态（状态、舵角、电机、链路、故障位）。`fetch` 轮询、失败重试、**切到后台或关页面自动请求停止**（`visibilitychange`） |
| **`/cmd` 支持 `servo=`** | `GET /cmd?move=F&servo=-30` 一条命令同时表达"前进 + 左舵"；`BuildWebCommand()` 把舵角/`turn` 应用到**所有**动作 |
| **keep-alive** | 响应头改 `Connection: keep-alive`，同一 TCP 连接上连续服务多个请求；否则每 400 ms 重建连接会和 ESP 的单客户端槽位打架 |
| **单缓冲内联渲染** | 响应头 + 正文都写在调用方**同一块**缓冲里（头部预留 160 B，`Emit()` 再前移正文）。此前 `body[1024]` 在**栈**上，而本机 `_Min_Stack_Size` 只有 **2048 B** —— 这是个真实的栈溢出隐患，现已消除 |
| **缓冲提升** | `HTTP_RESPONSE_BYTES` / `HTTP_RAW_BYTES` → 3072（控制页 2460 B） |
| **编译期防截断** | 新增 `typedef char kPageMustFit[...]` 静态断言：控制页一旦放不下**直接编译失败**。此前它被 `snprintf` 悄悄截断，页面缺掉尾部 `<script>`，浏览器表现成"没反应"，极难排查 |
| **连接代际计数** | 新增 `EspLink_ClientGeneration()`。应用只在**确实换了客户端**时清解析状态 —— 只比较 `IsClientConnected()` 或 client id 都不够（槽位会复用），**新客户端会继承旧客户端的 HTTP/协议模式**，实测踩到过 |

### D.3 现场实测（PC 经校园网直连，全部通过）

```
[1] 控制页完整性
    HTTP 200 ✓   含 </script> ✓   含 setInterval(tx,400) ✓   页面 2460 字节

[2] 连续前进 —— 同一条 keep-alive 连接，每 400ms 一次，共 10 次（跨 4 秒）
    step=1/link=1  ×10
    ---> 全程 step=1 且 link=1 ：电机 4 秒内从未被失联保护停过

[3] /cmd?move=F&servo=-30  -> step=1  servo=-30  link=1   （前进+左舵一条命令生效）

[4] /cmd?move=S&servo=0    -> step=0  servo=0

[5] 停发 1.5 秒（模拟关页面）-> step=0  servo=0  link=0  err=1
    ---> 安全网仍然有效，网页方便没有换来安全性下降

[6] 协议路径回归：<CMD,seq=200,move=F,..> -> <ACK,seq=200,result=OK> + step_on=1
    随后 GET /api/status -> 200 OK              （两条路径仍然共存）
```

### D.4 网页端能力边界（明确写清）

| 能做 | 说明 |
| --- | --- |
| 连续前进 | 点"前进（连续）"，页面自动轮询维持 |
| 转向 | 左舵 −30° / 直行 0° / 右舵 +30°，可与前进同时生效 |
| 停止 | 一键停止并回中舵机，同时终止轮询 |
| 实时状态 | 状态 / 舵角 / 电机 / 链路 / 故障位，每 400 ms 刷新 |
| 安全兜底 | 关页面、切后台、断网 → 1 秒内自动停机回中 |

**不支持（有意为之）**：调速。固件的 60/100 只是旧协议兼容字段，本机是固定低速输出，不声明真实 RPM。

### D.5 最终产物（第三轮）

```text
bionic_fish.bin  32,764 字节
SHA-256          d93820a781fcd83ccae72e176588e61f3fb4f6b800fa22af659fbc90fac99dad
Flash 49.99%    RAM 69.88% (14,312 / 20,480 B，含 2 KB 栈 + 512 B 堆)
STM32 宿主机测试 17/17 通过
烧录后回读校验：与本地 bin 逐字节一致
```

> RAM 从 49.84% 升到 69.88%，主要是三块 HTTP 缓冲（响应 3072 + 原始发送 3072 + 请求 192）。
> 仍然是静态分配、无堆分配，且栈占用已大幅下降（正文不再走栈）。若日后 RAM 吃紧，
> 优先缩减控制页体积，再同步调小 `HTTP_RESPONSE_BYTES`（静态断言会在放不下时报错）。

---

## 附录 E：2026-09-11 第四轮 —— 电机提速 1.5×、双档位与舵机左右对调

### E.1 电机提速 1.5×（用户要求：低速 60→90，高速 100→150）

转速与换相周期成反比，因此"提速 1.5×"= 周期 ÷ 1.5：

| 档位（旧协议 `step_speed`） | 原周期 | 现周期 | 说明 |
| --- | --- | --- | --- |
| 60（低速） | 50000 µs | **33333 µs** | `CFG_STEPPER_COMMUTATION_PERIOD_US`，1.5× |
| 100（高速） | （原先被忽略） | **20000 µs** | `CFG_STEPPER_FAST_PERIOD_US`，按 90:150 再缩 1.5× |

⚠️ **前提说明（重要）**：改动前固件是**单一固定速度**，`step_speed` 的 60/100 被刻意忽略
（安卓也已取消档位选择、固定发 60）。所以"高速 100"此前并不存在，本次是**把档位重新接回
换相周期**：`MotorController.commutation_period_us` 按命令的 `step_speed` 选择。

新增配置与校验：

```c
#define CFG_STEPPER_COMMUTATION_PERIOD_US  33333UL   /* 低速档 */
#define CFG_STEPPER_FAST_PERIOD_US         20000UL   /* 高速档 */
#if (CFG_STEPPER_FAST_PERIOD_US >= CFG_STEPPER_COMMUTATION_PERIOD_US)
#error "高速档周期必须小于低速档，否则 step_speed=100 会比 60 还慢。"
#endif
```

**换挡立即生效**（周期变化时重排换相时钟）；同档重复命令仍然**不**打乱时钟，
这条原有语义（C-1 的修复）保持不变。

### E.2 舵机左右对调

只反转"角度 → 脉宽"的极性（`servo_control.c` 的 `AngleToPulseUs`），**协议/UI 语义不变**
（左转仍是负角、右转仍是正角），因此上位机、网页、板载按键都无需改动，物理方向整体反转：

| 命令 | 对调前脉宽 | 对调后脉宽 |
| --- | --- | --- |
| −30°（左） | 1000 µs | **2000 µs** |
| 0°（回中） | 1500 µs | 1500 µs（不变） |
| +30°（右） | 2000 µs | **1000 µs** |

限幅与回中仍在原处，因此 `Servo_Center` 与 ±30° 边界不受影响。

### E.3 网页端新增档位按钮

控制页增加「慢档 / 快档」，对应 `/cmd?...&speed=60|100`。状态区新增 `换相周期: N us`，
可直接读出当前档位（33333 = 慢档，20000 = 快档）。`/api/status` 也新增 `period=`。

### E.4 现场实测（烧录后，PC 经校园网 keep-alive 直连）

```
PASS  控制页含慢/快档按钮（id=V1/id=V2，页面完整含 </script>）
PASS  慢档  -> step=1  period=33333      ← 原 50000 的 1.5×
PASS  快档  -> step=1  period=20000
PASS  切回慢档 -> period=33333
PASS  前进+左舵同一条命令 -> servo=-30 step=1
PASS  停止 -> step=0
PASS  连续前进（快档）每 400ms × 8 次（跨 3.2 秒）-> 全程 s1/p20000
结果: PASS=7 FAIL=0
```

**舵机物理方向**未能用仪器验证：本机 `STM32_Programmer_CLI -r32` 读外设寄存器一律返回 0
（工具/调试通路限制），无法读 TIM3_CCR1。方向对调由宿主机测试精确覆盖（脉宽映射逐值断言），
**实机方向请目视确认一次**。

### E.5 ⚠️ 新增的陷阱：用调试器 halt 内核会打断 CIPSEND，把 ESP 卡死

本轮为了读 TIM3 寄存器反复 `-r32`（会 **halt 内核**），其中一次刚好冻在固件发出
`AT+CIPSEND=0,N` 之后、载荷入队之前。ESP 于是停在"等 N 字节载荷"状态并吞掉一切输入，
随后复位也没救回来，只能断电。串口证据：`reset=1 error=AT probe timeout`、`uloss=0`。

- **教训**：不要在链路活跃时用调试器暂停内核；要读外设请在链路空闲（如 ESP 未配置、`tcp=0`）时做。
- 这也再次印证了既有的设计约束：**ESP 一旦进入未完成的 CIPSEND 数据阶段，软件无法自证恢复，
  只能断电**（板子未接 ESP 的 EN/RST）。该状态在 `esp_link.c` 里以 `NeedReset()` 锁存，属**有意**行为。
- **建议的后续加固**（本轮未做）：`AT` 探测连续失败时，先送出**一批空格填充**（例如 1024 字节）
  去凑满可能挂起的 CIPSEND 载荷，再重试探测；空格不是合法 AT 命令，不会误触发动作，
  且与现有 `abandon_send` 的"等长空格补齐"手法一致。这能把"必须断电"降级为"自动重试"。

### E.6 测试影响（4 类断言更新，均为**有意**的行为变更）

1. `motor_host_test.c` 整体重写：新增"换挡立即生效"与"同档不重排时钟"两组断言；
   期望值改用 `SLOW_US`/`FAST_US` 常量，不再写死 50000。并锁定
   `CFG_STEPPER_COMMUTATION_PERIOD_US == 33333` 与 `CFG_STEPPER_FAST_PERIOD_US == 20000`。
2. `app_host_test.c` 中所有"±30° → 脉宽"的断言按对调后的极性翻转（左=MAX、右=MIN）。
3. `+15°` 的期望由 1750 µs 改为 1250 µs。
4. `TestFixedLowRunAndStop` 原先在 2 秒内交替 `step_speed` 60/100 并断言固定 41 次换相；
   由于换挡现在会重排时钟，改为**固定 60 档**，断言换成"理论上限 −2 次"的区间
   （实测 59，理论上限 61，差在起始对齐）。该区间仍足以捕获速度回归：
   若周期被改回 50000，次数会掉到 ~41。

### E.7 产物（第四轮）

```text
bionic_fish.bin  33,136 字节
SHA-256          401f6066af08e40c213689a3e782ebffdc71bda9ee9f9fb68f93b1e2f8ebad66
Flash 50.56%    RAM 74.96% (15,352 / 20,480 B，含 2 KB 栈 + 512 B 堆)
STM32 宿主机测试 17/17 通过
烧录后回读校验：与本地 bin 逐字节一致
```

> RAM 再到 74.96%：控制页加档位按钮后超出 3072 缓冲，**编译期静态断言如期报错**（设计生效），
> 于是精简了一次页面并把缓冲提到 3584。目前剩余约 5.1 KB 空闲 + 2 KB 栈，仍然安全；
> 但后续若继续给页面加功能，应先看这条断言，而不是直接改缓冲。

---

## 附录 F：2026-09-22 第五轮 — 推进方案由步进改为两路直流减速电机

> 本轮是一次**换执行器**的改动：把「42 两相双极步进 + TB6612 双桥软件四拍换相」换成
> 「M1 = 370 直流减速电机（尾段推进）+ M2 = N20（12V 版）直流减速电机（唧筒活塞）」，两路各自独立启停与换向；
> 同时把舵机安全行程由 ±30° 收窄为 ±20°。

### F.1 关键口径（先看这三条，别的都可以后读）

| 项目 | 结论 |
| --- | --- |
| PWM 还用不用？ | **用**。TB6612 是双 H 桥直流驱动，`PWMA/PWMB` 给占空比、`AIN/BIN` 给方向。VM 接 12V 指的是**供电**，电机两端得到的是「12V × 占空比」的平均电压；**不能绕过 TB6612 把电机直连 12V**。 |
| 默认占空比 | **M1 = 100%、M2 = 100%**（`CFG_MOTOR_A/B_DUTY_PERCENT`）。100% 在 F1 上落成 `CCR = ARR+1 `→` 输出恒高，即满压；它不是限流保护。 |
| N20 风险 | 所用 N20 为 **12V 版本**（唧筒驱动，V1.0.0 已实装验证）。若换成 6V 版本，必须先降占空比（约 50%）或改供电，否则超压。 |

### F.2 改动清单（按交付大类）

1. **驱动层**：`motor_control.h/.c` 由四拍换相表整体重写为「两路方向状态机」—`Motor_SetDirections` / `Motor_ApplyFailsafe` / `Motor_SetRunning` / `Motor_ApplyCommand`，删除 `step_phase`、`next_commutation_us`、`commutation_period_us` 与 `Motor_Service`。`app_config.h` 删除全部 `CFG_STEPPER_*`，新增 `CFG_MOTOR_A/B_DUTY_PERCENT`、`CFG_MOTOR_A/B_ENABLED` 与编译期门禁。`bsp_board.c` 未改（桥抽象本就可复用）。
2. **协议与网页**：CMD 新增**可选**字段 `m2=F|R|S`（**缺省 = 停止**）；`move=R` 放开；`step_speed` 降级为不改变占空比的兼容字段。STA 在 `err` 之前追加 `m1=` / `m2=`，**其余字段与顺序完全不变**。局域网控制页改为两组「前进/停止/后退」按钮，轮询 URL 带 `m2=`。
3. **舵机**：新增 `CFG_SERVO_FULL_SCALE_DEG=30` 作为脉宽换算基准，`CFG_SERVO_SAFE_*` 收窄到 ±20°；`servo_control.c` 改用满量程基准换算，所以 ±20° 只给出满量程 2/3 的偏移（左 1833 µs / 右 1167 µs / 0° 仍 1500 µs），**不再出现 1000/2000 µs 端点**。
4. **安卓端**：本轮**不改源码**，交付改造方案 `仿生鱼安卓_v0.4.0_交付包/Android工程/docs/双电机控制与舵机20度_安卓端改造方案.md`（文件级改动清单 + 四向兼容矩阵）。

### F.3 测试与验证

- host 侧 **17/17 通过**：10 个可执行（`protocol` / `esp_link` / `motor` / `motor_disabled` / `bsp_pwm` / `sensor_oled` ×3 / `app` / `app_disabled`）+ 7 个编译期门禁（`config_motor_a/b_*`、`config_vacuous_imu`）。
- `motor_host_test` 重写为 9 格方向矩阵 × 4 种配置，断言两路方向、各自占空比与 `brake_calls == 0`。
- `app_host_test` 新增 `TestDualMotorIndependent`、`TestM2OptionalField`，并让 `move=R` 从"必须被拒"改为"必须真驱动"。
- `bsp_pwm_host_test` 新增 **100% 占空比**用例（此前只覆盖 10%），并把模型里"驱动时占空比必须 ≤ 10%"的过时不变式换成「只有 duty 提交后才允许置方向位」。
- 本机 GCC 15.2 下 `esp_link_host_test` 仍会命中既有的 `-Wformat-truncation`（6-3），按该节建议**仅命令行加 `-Wno-error=format-truncation`，未改 `CMakeLists.txt`**。

### F.4 本轮修掉的真实缺陷（都由测试/核对暴露）

| 缺陷 | 后果 |
| --- | --- |
| `RefreshSnapshot` 漏了 `s_snapshot.motor_b` 与 `step_running` 两行 | `motor_b` 永不赋值、`memset` 后恒为 0（= `BF_MOVE_FORWARD`），**STA 与网页会永久把 M2 报成"前进"** |
| `app.c` 残留 3 处 `s_motor.step_running` + 3 处 `Motor_Service` | **app.c 根本编译不过**（已删字段/函数） |
| `ServiceDebugButtons` 记录的是"按键意图"而非"调用后状态" | 驱动被编译期禁用时会打印 `DEBUG K1 M1 ON` 却没真的转 |

### F.5 未完成 / 待实测（不要当成已完成）

> ⚠️ **本节是 §F 改写当时（2026-09-23）的历史快照。其中第 1、2 条已在 V1.0.0 完成**：Arm 交叉构建已重做（见 README 验收边界的 BIN 尺寸与 SHA-256）、Android v0.5.0 已实现 `m2=` 与 ±15°。第 3–5 条的处置状态见各自条目。

1. **Arm 交叉构建与烧录未做**：本机 `PATH` 内没有 `arm-none-eabi-gcc` / `cmake` / `ninja` / `STM32_Programmer_CLI`。README 与验收清单里改动前的 **BIN 尺寸与 SHA-256 已失效**，必须重新构建后再引用。　→ **V1.0.0 已完成**。
2. **安卓源码未改**（本轮非目标）：只交付了改造方案；`m2` 与 ±20° 要在 APK 侧真正可用，需按方案实施并升版本。　→ **V1.0.0 已完成**：Android v0.5.0（versionCode 7）已实现 `m2=` 与 ±15°。
3. **旧 APK 的 ±30° 预设会被新固件回 `E_RANGE`**：这是收窄行程的直接后果，方案文档给了 A/B/C 三个处置选项，**待产品决策**。
4. **实板风险**：满速挡（95%）下 370 电机的堵转电流与 TB6612 温升（TB6612 **无过流保护**）；两路电机实际转向与机械方向是否一致；N20 唧筒活塞限位与动密封。
5. `allowReverseCommand` 在安卓侧默认仍为 `false`，是否放开需产品确认（方案文档已列为高风险项）。

### F.6 命名遗留（故意的，不要"顺手改"）

- `PROTO_ERR_STEPPER_DISABLED` / `E_STEPPER_DISABLED`、`BF_FAULT_STEPPER_DISABLED` 三个名字沿用**错误码词表与故障位号**，改名会破坏旧客户端兼容；语义现在分别是"某路电机被禁用"与"M1 被编译期禁用"。
- `CFG_JY61P_*`、`jy61p.*` 同理（实物是 JY901S），见 4.3。

---

## 附录 G：2026-09-23 第六轮（v0.5）— 2 s 慢周期 PWM + 95%/60% 双挡位 + 舵机 ±15° + 网页控制页重做

> 本轮解决两个现场问题：**#1 TB6612 带不动直流减速电机**；**#2 IP 直连网页控制页仍是旧的快慢速挡，且舵机左右反向、角度未改 15°**。

### G.1 问题 #1 的根因与处置

**现场条件**（用户确认）：**STBY 已接高电平**、**VM = 12 V**，负载在低速挡（旧 20 kHz + 100%）时带不动。

**根因**：100% 占空比在 STM32F1 上落成 `CCR = ARR + 1`，TIM2 比较输出**恒为高、永不翻转**。TB6612 的 PWM 输入需要持续开关边沿维持高侧栅极/自举驱动；恒定高电平使自举电容得不到刷新，高侧无法持续导通 → 驱动能力弱，带载即掉。

**处置（两条同时上）**：

| 项 | 旧值 | 新值 | 理由 |
| --- | --- | --- | --- |
| TIM2 载波周期 | 20 kHz（50 µs） | **2000 ms（2 s）** | 用户明确要求"2 s 一周期、满速满扭驱动"；周期拉长后边沿稀疏、便于示波器观察，且与低速挡效果解耦 |
| 满速挡占空比 | 100% | **95%** | 保证每个 2 s 周期都有一次完整低电平沿 → 自举可刷新；95% × 12 V = 11.4 V，转速扭矩几乎无损 |
| 低速挡占空比 | （无独立挡位，`step_speed` 已被架空） | **60%** | 恢复"低速挡"语义，与满速挡共用同一挡位开关 |

**关键实现点**：周期从 50 µs 变成 2 s 后，`SetBridgeCompare()` 若继续"写 CCR 后等定时器自然更新（UEV）才返回"，**单次调用最长会阻塞 2 s**。改为写入后立即发一次 `HAL_TIM_GenerateEvent(&htim2, TIM_EVENTSOURCE_UPDATE)` 强制提交影子寄存器，命令延迟回到毫秒级。

> 注意：`__HAL_TIM_GENERATE_EVENT` 这个宏在 STM32F1 HAL 里**不存在**，Arm 构建会报隐式声明；必须用 `HAL_TIM_GenerateEvent()` 函数形式。

### G.2 问题 #2 的处置：网页控制页重做

| 项 | 旧 | 新 |
| --- | --- | --- |
| 电机控件 | 一组"快/慢挡 + 前进/停止/后退" | **电机1：启动/停止/反转 三键；电机2：启动/停止/反转 三键**（按钮 ID `A1`/`A0`/`AR`、`B1`/`B0`/`BR`） |
| 低速挡 | 与 `step_speed` 混在一起 | 独立 **「60% 低速挡」复选框**（ID `LOW`）；勾选后两路同降速，轮询 URL 带 `&speed=60`，否则 `&speed=100` |
| 舵机角度 | `SM=20` | **`SM=15`** |
| 舵机左右映射 | **反的**（网页左键实际右转） | 修正：左键发 `SM`（正角）、右键发 `-SM`（负角），高亮逻辑同步（`sv>0` 亮左、`sv<0` 亮右） |

**反向的成因**：固件在与上位机对接的那一层已经做了 `angle = -angle` 取反，而网页端又按"左=负"的直觉发了一次负值，两次取反相互抵消。修法是在**网页层**改回与固件一致，**不再动固件的取反逻辑**——极性反转只允许存在于一层。

`HTTP_RESPONSE_BYTES` 由 3584 提升到 **4096**：新页面约 3341 字节 + 响应头预留 160 字节，超过旧缓冲，编译期门禁 `kPageMustFit` 会直接报负数组长度——这是该门禁在正常工作。

### G.3 改动文件清单

| 文件 | 改动 |
| --- | --- |
| `app/Inc/app_config.h` | TIM2 改 2 s（`CFG_MOTOR_TIM_PRESCALER=7199` / `CFG_MOTOR_TIM_PERIOD=19999`，`CFG_MOTOR_PWM_PERIOD_MS=2000`）；新增 `CFG_MOTOR_FULL_DUTY_PERCENT=95` / `CFG_MOTOR_LOW_DUTY_PERCENT=60`；`CFG_MOTOR_A/B_DUTY_PERCENT` 改为可选覆盖（缺省=满速挡）；舵机 `CFG_SERVO_SAFE_MIN/MAX_DEG=∓15`；新增 `CFG_MOTOR_STBY_PIN_ENABLED`（默认 0）；旧 TIM2 频率断言换成 2 s 周期断言链，并新增挡位/STBY/占空比取值校验 |
| `Core/Inc/main.h` | 新增可选 `TB6612_STBY_Pin` == PB5；注释由"42 两相步进线圈"更正为双直流电机 |
| `bsp/Inc/bsp_board.h` / `bsp/Src/bsp_board.c` | 新增 `BspDutyMode`（`BSP_DUTY_FULL`/`BSP_DUTY_LOW`）与 `BSP_Board_SetDutyMode` / `BSP_Board_GetDutyMode` / `BSP_DutyPercentFor`；`SetBridgeCompare` 改为 UG 立即提交；`BSP_Board_Init` 可选配置并拉高 STBY |
| `control/Src/motor_control.c` | 占空比由编译期常量改为运行时挡位查询 `BSP_DutyPercentFor(BSP_Board_GetDutyMode())` |
| `control/Src/servo_control.c` | 注释更新为 ±15°；取反逻辑位置写明"只在一层做" |
| `protocol/Src/http_ui.c` / `protocol/Inc/http_ui.h` | 页面整体重做（双电机各三键 + 低速挡复选框 + `SM=15` + 左右修正）；`HTTP_RESPONSE_BYTES` 3584 → 4096 |
| `app/Src/app.c` | `ApplyAcceptedCommand` 先按 `step_rpm`（60→低速挡、其余→满速挡）设置挡位再套用方向；`BuildWebCommand` 把 `speed=60` 映射为 `step_rpm=60`，否则 100 |
| `tests/host/**` | `app_host_test` / `motor_host_test` 补挡位桩、更新按钮 ID 与 `speed=` 断言、新增双电机+挡位用例；`bsp_pwm_host_test` 按新算法整体重写（补 `HAL_TIM_GenerateEvent`/`HAL_GPIO_Init` 桩、`PERIOD_TICKS=20000`）；`pwm_stubs/stm32f1xx_hal.h` 补 GPIO 与事件类型；`prococol_host_test` 舵机边界改 ±15/±16 |
| 文档 | `README.md` / `硬件引脚与驱动说明.md` / `通信协议.md` / `验收检查清单.md` 同步更新 |

### G.4 本轮验证

- **Arm 交叉构建成功**（本轮新建独立构建目录 `build-fw-v05/`，避免污染旧产物）：

| 产物 | 字节数 | SHA-256 |
| --- | ---: | --- |
| `bionic_fish.bin` | 34,272 | `517de91e10540754bc03fd987b93b84e0c95b470b07cddf15c9a4319102fa635` |
| `bionic_fish.elf` | 68,072 | `36f214ea2a33570ec0845695bf4f512b3690a4e8888336a6a724c67e09ed5f12` |

  占用：Flash **52.29%**（34,272 / 65,536 B）、RAM **77.42%**。

- **host 测试 16/16 通过**（含编译期门禁）。
- `esp_link_host_test` 仍是既有的 `-Wformat-truncation` 问题（见 §6-3），按该节建议仅命令行加 `-Wno-error=format-truncation`，**未改 `CMakeLists.txt`**。

### G.5 本轮修掉的真实缺陷

| 缺陷 | 后果 |
| --- | --- |
| 100% 占空比 → `CCR > ARR` → 输出恒高、无下降沿 | **TB6612 带不动电机的直接原因**（本轮主目标） |
| `SetBridgeCompare` 等自然更新提交 | 周期改 2 s 后**单次调用最多阻塞 2 s**，命令延迟不可接受 |
| `__HAL_TIM_GENERATE_EVENT` 在 F1 HAL 不存在 | Arm 构建隐式声明；改用 `HAL_TIM_GenerateEvent()` |
| 网页舵机左右双重取反 | 网页左键实际右转 |
| 页面增长超过 `HTTP_RESPONSE_BYTES` | 编译期 `kPageMustFit` 负数组长度报错（门禁正常发挥） |
| `http_ui.c` 字符串拼接里混入 C 注释 | 字面量被截断，页面破损 |

### G.6 待实测（不要当成已完成）

1. **实板带载驱动**：2 s 慢周期 + 95% 占空比下，370 电机带动鱼尾能否稳定启动并维持；建议用示波器/万用表确认 PWMA 每 2 s 有一次完整低电平沿。
2. **堵转电流与 TB6612 温升**：TB6612 无过流/短路保护规格，满速挡长期运行必须实测。
3. **N20 唧筒集成**：12V 额定已在 V1.0.0 实装验证；活塞行程两端的微动开关限位接线与整机动密封仍待整机联调确认。
4. **两个 2 s 周期的边沿稀疏性风险**：慢周期下 PWM 平均电压建立慢，若电机在低速挡出现"一顿一顿"，优先怀疑这是慢周期而非驱动故障，可临时把 `CFG_MOTOR_PWM_PERIOD_MS` 调小做对照实验。
5. 若实测证明 TB6612 在恒高输入下也能稳定驱动（即根因判断有误），把 `CFG_MOTOR_FULL_DUTY_PERCENT` 改回 100 即可，其余逻辑不变。

### G.7 未做（明确边界）

- **安卓侧已同步**：Android v0.5.0（versionCode 7）已实现 `m2=` 字段（`AsciiProtocol.kt` 编码 + M2 独立按键组 + M2 遥测行），与固件 `m2=` 语义对齐，可正确控制 N20 唧筒。更早的旧 APK（v0.4.0/6）不发送 `m2`，其 ±20/±30° 预设会被新固件回 `E_RANGE`，需升级。
- 板上调试键仍未提供 M2 控制（已知功能缺口，实体侧仅 M1 与舵机）。

---

## 附录 H：2026-09-23 第七轮 — Wi-Fi 模式回归修复（CWMODE 3 → 2）

### H.1 用户报告的现象

手机连上 `BionicFish-AP` 后，IP 直连网页控制页 `192.168.4.1:9000` 完全打不开。用户明确提示：**「下午修改代码之前这个问题不存在」**——这是一条决定性的排查线索。

### H.2 定位过程：跨提交 diff

这条线索意味着**先查 Git 时间线，不要在软件逻辑里猜**。时间线：

```
a070a26 | 09-23 15:17 | docs(v0.5): 清除源码注释里的步进口径与过时挡位描述
5bd9bf0 | 09-23 15:03 | docs(v0.5): 安卓端改造方案对齐…
619ca36 | 09-23 15:02 | chore: 移除旧版交付目录 v0.3.1
f30f511 | 09-23 15:01 | feat(v0.5): 2s 慢周期 PWM + 95%/60% 双挡位 + 舵机 ±15° + 网页控制页重做  ← 回归引入点
9b97230 | 09-09 22:39 | fix: stabilize TCP control… （最后的已知可用版本）
```

**坑**：`f30f511` 里所有文件都显示为**全新增（+N, -0）**，因为 v0.5 目录是新建的，所以 `git show f30f511` 看不到 diff。**必须跨提交用旧路径对比**：

```bash
git show 9b97230:"仿生鱼完整项目交付包_v0.3.1/仿生鱼完整项目交付包/STM32控制工程/bsp/Src/esp_link.c" > /tmp/old_esp.c
```

### H.3 决定性 diff

| | 旧版 `9b97230`（可用） | 新版 `f30f511`（故障） |
| --- | --- | --- |
| `SET_MODE` 下发 | `AT+CWMODE_CUR=2` / `AT+CWMODE=2`（**写死纯 AP**） | `AT+CWMODE_CUR=%u`，实参 `CFG_ESP_WIFI_MODE`=**3** |
| `CFG_ESP_WIFI_MODE` 宏 | **不存在** | 新增，默认 `3U`（`app_config.h:50`） |
| `SET_CHECK_STA_IP` | **0 处** | **3 处**（新增步骤，双模下反复拿到 `0.0.0.0`） |
| `AT+CWJAP`（STA 配网） | 无 | **仍然无** ⇒ 配置自相矛盾 |
| `app.c` 里的 HTTP 代码 | **完全没有** | 新增整套 HTTP（v0.5 新功能） |

### H.4 根因

v0.5 让固件下发 `AT+CWMODE=3`（AP+STA），却**从不下发 `AT+CWJAP`**。ESP-01S 于是去连 flash 里的旧 AP，连不上 ⇒ `sta=0.0.0.0`（串口已证实）；双模下 ESP-01S（仅 1 MB flash）内存紧张，还要同时维护 AP-DHCP + `CIPSERVERMAXCONN=4`，导致手机侧拿不到 IP 或 AP 转发失效 ⇒ 页面打不开。

**教训**：前两轮我怀疑的「ESP 残留 `ResetNeeded`」「USART2 TX 饥饿」**都是错的**，串口实测 `error=OK`/`reset=0` 已把两者推翻。正确路径是 **「下午改之前是好的」⇒ 立刻跨提交 diff 配置项**。

### H.5 修改内容

| 文件 | 改动 |
| --- | --- |
| `app/Inc/app_config.h` | `CFG_ESP_WIFI_MODE` **`3U` → `2U`**，并重写上方注释块记录回归根因与恢复条件 |
| `tests/esp_link/esp_link_host_test.c` | ① 加 `#include "app_config.h"` ② 写死的 `"AT+CWMODE=3"` 改为引用 `CFG_ESP_WIFI_MODE` 宏 ③ STA IP 断言按模式分支（纯 AP 下跳过） |

**为什么测试也要改**：原测试写死了 `"AT+CWMODE=3"`，改配置后必然报错——**写死值会把「配置变更」误报成「功能回归」**，下次改配置还会再失效。改为引用宏后可自动跟随。

### H.6 验证证据

| 验证项 | 结果 |
| --- | --- |
| Arm 交叉构建 | `build-fw-fix/bionic_fish.bin` 34,272 B，SHA-256 `333e4a52…`（Flash 52.29% / RAM 77.42%） |
| 反汇编常量确认 | `8001c12: 2302  movs r3, #2`（旧固件同址为 `2303`），证明常量真正进了固件 |
| host 测试 | **10/10 全部 PASS** |
| 实板烧录 | 下载 33.47 KB，`Download verified successfully`，MCU 复位成功 |
| 独立回读校验 | 回读 34,272 字节，SHA-256 与本地**完全一致** |
| USART3 运行观测 | 连续 20 s：`server=1`、`error=OK`、`reset=0`、`uloss=38`（冻结不增长）、`st=0` |

### H.7 烧录遇阻与硬件定论

本轮烧录一度全程报 `Error: failed to erase memory` / `failed to download Sector[0]`。对照实验结论：

| 操作 | 结果 |
| --- | --- |
| 写/读 **RAM** `0x20000000` | ✅ 全部成功 |
| 写/读 **flash** `0x08000000` | ❌ 全部失败（连 4 字节都读不出） |
| OB 选项字节 | RDP 无保护、WRP0..31 全部未写保护 |
| 5 组 SWD 频率 × 3 种复位模式 × 2 个 CubeProgrammer 版本 | ❌ 同一个错 |

RAM 与 flash 挂在同一条总线上，**RAM 完全可用而 flash 读擦写全废** ⇒ 指向 **MCU 内部 flash 控制器故障**，与代码/探针/接线均无关。更换同型号芯片后立即恢复正常。

**注意**：`-e all` 会报「Mass erase successfully achieved」，但紧随其后的扇区擦除照样失败——**不要把这个成功报文当作擦除生效的证据**。

### H.8 遗留问题（本轮未修）

**App 端连上就断、反复重连**，代码层已定位两个成因：

1. **`AT+CIPSTO=3`**（`bsp/Src/esp_link.c:494`）：ESP 服务端 3 秒收不到数据就主动断开客户端。App 在 `desired == null` 时只 `delay` 不发帧（`DefaultBionicFishRepository.kt:674-676`），切后台/进设置页/安全停车后出现 3 秒空窗即被断开。**旧版同样是 3，非本次回归**，是一直埋着的隐患。
2. **固件只接受一个控制客户端**（`bsp/Src/esp_link.c:250`，`L.client < 0` 才接受）：安卓与网页同时连、或重连时旧连接未被 ESP 回收，新连接会被立刻 `AT+CIPCLOSE`。

**接线判据**：串口 `uloss=`（USART2 RX 丢字节计数）若在运行中持续增长才说明杜邦线接触不良；实测 `uloss=38` 冻结不增长 ⇒ 当前静态接线正常，**不必归因于接线**。

### H.9 文档同步

`README.md`（新哈希表 + 回归修复段 + App 断连 + 烧录硬件注意）、`硬件引脚与驱动说明.md`（新增 §3.5 Wi-Fi 模式必须为纯 AP）。

---

## 附录 I：2026-09-23 第八轮 — HTTP 响应缓冲不足导致网页打不开

### I.1 现象

CWMODE 修好、固件已烧入实板后，手机连上 `BionicFish-AP` 仍然打不开 `http://192.168.4.1:9000/`。串口显示 `server=1`（9000 端口在监听）、`error=OK`、`reset=0`、`uloss` 稳定，看不出任何异常。

### I.2 定位：两个缓冲区尺寸对不上

| 缓冲区 | 位置 | 大小 |
| --- | --- | ---: |
| `response[]`（`HTTP_RESPONSE_BYTES`） | `app/Src/app.c:507` | 4096 |
| `L.raw[]`（`HTTP_RAW_BYTES`） | `bsp/Src/esp_link.c` | **3584** ← 少 512 |

实际响应长度（用 `arm-none-eabi-objdump -t` 从符号表读出 `kPage` = `0x0e44` = 3652）：

```
123 (kHttpOkHtml 响应头) + 4 (Content-Length 位数) + 3652 (页面) = 3779 字节
3779 > 3584  ==>  超出 195 字节
```

`EspLink_SendRaw` 的第一道守卫就是 `length > sizeof(L.raw)`，条件成立即**直接 `return false`**：

```c
if ((data == NULL) || (length == 0U) || (length > sizeof(L.raw)) ||
    !EspLink_IsClientConnected()) {
    return false;
}
```

⇒ 响应一个字节都发不出去，浏览器只能一直转圈直到超时。

### I.3 为什么极难排查

**整个失败是完全静默的**：`SendRaw` 只返回 `false`，调用方 `ServiceHttpRequest` 丢弃返回值（`(void)EspLink_SendRaw(...)`），既不设故障位也不打日志。串口上 `error` 仍是 `OK`、`reset=0`、`uloss` 不涨；`tcp` 也会因客户端超时退出而回到 0。所有可见指标都"正常"，唯独页面出不来。

**根因是 v0.5 的网页重做**：页面从旧版涨到 3652 字节，但当时只把 `HTTP_RESPONSE_BYTES` 从 3584 提到了 4096，**忘了同步 `HTTP_RAW_BYTES`**。而 `esp_link.c` 里那句注释「必须 >= HTTP_RESPONSE_BYTES」当时只是注释，没有任何强制手段。

### I.4 修复

1. `bsp/Src/esp_link.c`：`HTTP_RAW_BYTES` **3584 → 4096**
2. 同文件新增编译期门禁，并 `#include "http_ui.h"` 以取得常量：

```c
typedef char kHttpRawMustFitResponse[(HTTP_RAW_BYTES >= HTTP_RESPONSE_BYTES) ? 1 : -1];
```

**门禁已实测有效**：把 `HTTP_RAW_BYTES` 临时改为 2048 后构建报错
`error: size of array 'kHttpRawMustFitResponse' is negative`，改回 4096 即通过。
今后再出现"传输缓冲 < 响应缓冲"会在构建期就失败，不会再退化成运行期静默丢包。

### I.5 验证证据

| 验证项 | 结果 |
| --- | --- |
| .bss 尺寸变化 | `L` 结构 `0x14d4`(5332) → `0x16d4`(5844)，**正好 +512** |
| Arm 构建 | 成功，`build-fw-http/bionic_fish.bin` 34,272 B，SHA-256 `25595921…` |
| RAM 占用 | 77.42% → **79.92%**（16,368 / 20,480 B），仍有约 4 KB 余量 |
| host 测试 | **10/10 全部 PASS** |
| 编译期门禁 | 故意改小后构建按预期失败 |
| 实板烧录 | `Download verified successfully`，MCU 复位成功 |
| 独立回读 | 34,272 字节 SHA-256 与本地产物**完全一致** |

### I.6 本轮教训

**"缓冲区尺寸对不上"这类问题必须由编译期拦住。** 靠注释写"必须 >= 另一个宏"是无效约束——v0.5 的注释就是这么写的，依然漏了。凡是两个宏之间存在必须成立的大小关系，就应写成 `typedef char guard[(A >= B) ? 1 : -1];`。

另外，**发送路径的返回值不要随手丢弃**。本次 `(void)EspLink_SendRaw(...)` 把唯一的失败信号吞掉了，是排查困难的主因。至少应设一个故障位或计数。

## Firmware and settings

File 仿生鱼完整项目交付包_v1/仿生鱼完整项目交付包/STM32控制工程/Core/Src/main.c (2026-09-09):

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
#include "main.h"

/* USER CODE BEGIN Includes */
#include "app_config.h"
#include "app.h"
#include "bsp_board.h"
#include "bsp_time.h"
#include "bsp_uart.h"
/* USER CODE END Includes */
#include "gpio.h"
#include "tim.h"
#include "usart.h"

static void SystemClock_Config(void);

/* USER CODE BEGIN PD */
/* app_config.h 中的数值在这里映射为 HAL 枚举，避免 PLL/APB 设置与配置表脱节。 */
#if (CFG_PLL_MULTIPLIER == 2UL)
#define APP_PLL_MULTIPLIER RCC_PLL_MUL2
#elif (CFG_PLL_MULTIPLIER == 3UL)
#define APP_PLL_MULTIPLIER RCC_PLL_MUL3
#elif (CFG_PLL_MULTIPLIER == 4UL)
#define APP_PLL_MULTIPLIER RCC_PLL_MUL4
#elif (CFG_PLL_MULTIPLIER == 5UL)
#define APP_PLL_MULTIPLIER RCC_PLL_MUL5
#elif (CFG_PLL_MULTIPLIER == 6UL)
#define APP_PLL_MULTIPLIER RCC_PLL_MUL6
#elif (CFG_PLL_MULTIPLIER == 7UL)
#define APP_PLL_MULTIPLIER RCC_PLL_MUL7
#elif (CFG_PLL_MULTIPLIER == 8UL)
#define APP_PLL_MULTIPLIER RCC_PLL_MUL8
#elif (CFG_PLL_MULTIPLIER == 9UL)
#define APP_PLL_MULTIPLIER RCC_PLL_MUL9
#elif (CFG_PLL_MULTIPLIER == 10UL)
#define APP_PLL_MULTIPLIER RCC_PLL_MUL10
#elif (CFG_PLL_MULTIPLIER == 11UL)
#define APP_PLL_MULTIPLIER RCC_PLL_MUL11
#elif (CFG_PLL_MULTIPLIER == 12UL)
#define APP_PLL_MULTIPLIER RCC_PLL_MUL12
#elif (CFG_PLL_MULTIPLIER == 13UL)
#define APP_PLL_MULTIPLIER RCC_PLL_MUL13
#elif (CFG_PLL_MULTIPLIER == 14UL)
#define APP_PLL_MULTIPLIER RCC_PLL_MUL14
#elif (CFG_PLL_MULTIPLIER == 15UL)
#define APP_PLL_MULTIPLIER RCC_PLL_MUL15
#elif (CFG_PLL_MULTIPLIER == 16UL)
#define APP_PLL_MULTIPLIER RCC_PLL_MUL16
#else
#error "CFG_PLL_MULTIPLIER 必须在 STM32F1 支持的 2..16 范围内。"
#endif

#if (CFG_APB1_DIVIDER == 1UL)
#define APP_APB1_DIVIDER RCC_HCLK_DIV1
#elif (CFG_APB1_DIVIDER == 2UL)
#define APP_APB1_DIVIDER RCC_HCLK_DIV2
#elif (CFG_APB1_DIVIDER == 4UL)
#define APP_APB1_DIVIDER RCC_HCLK_DIV4
#elif (CFG_APB1_DIVIDER == 8UL)
#define APP_APB1_DIVIDER RCC_HCLK_DIV8
#elif (CFG_APB1_DIVIDER == 16UL)
#define APP_APB1_DIVIDER RCC_HCLK_DIV16
#else
#error "CFG_APB1_DIVIDER 必须为 1/2/4/8/16。"
#endif

#if (CFG_APB2_DIVIDER == 1UL)
#define APP_APB2_DIVIDER RCC_HCLK_DIV1
#elif (CFG_APB2_DIVIDER == 2UL)
#define APP_APB2_DIVIDER RCC_HCLK_DIV2
#elif (CFG_APB2_DIVIDER == 4UL)
#define APP_APB2_DIVIDER RCC_HCLK_DIV4
#elif (CFG_APB2_DIVIDER == 8UL)
#define APP_APB2_DIVIDER RCC_HCLK_DIV8
#elif (CFG_APB2_DIVIDER == 16UL)
#define APP_APB2_DIVIDER RCC_HCLK_DIV16
#else
#error "CFG_APB2_DIVIDER 必须为 1/2/4/8/16。"
#endif

#if (CFG_SYSCLK_HZ <= 24000000UL)
#define APP_FLASH_LATENCY FLASH_LATENCY_0
#elif (CFG_SYSCLK_HZ <= 48000000UL)
#define APP_FLASH_LATENCY FLASH_LATENCY_1
#elif (CFG_SYSCLK_HZ <= 72000000UL)
#define APP_FLASH_LATENCY FLASH_LATENCY_2
#else
#error "CFG_SYSCLK_HZ 超过 STM32F103 的 72 MHz 上限。"
#endif
/* USER CODE END PD */

int main(void)
{
    HAL_Init();
    SystemClock_Config();

    MX_GPIO_Init();
    MX_TIM2_Init();
    MX_TIM3_Init();
    MX_TIM4_Init();
    MX_USART2_UART_Init();
    MX_USART3_UART_Init();

    /* USER CODE BEGIN 2 */
    BSP_Time_Init();
    App_Init();
    /* USER CODE END 2 */

    while (1) {
        /* USER CODE BEGIN 3 */
        /* 解析、控制、UI 和超时检查都在这里运行；中断不做阻塞业务。 */
        App_Process();
    }
    /* USER CODE END 3 */
}

static void SystemClock_Config(void)
{
    RCC_OscInitTypeDef RCC_OscInitStruct = {0};
    RCC_ClkInitTypeDef RCC_ClkInitStruct = {0};

    RCC_OscInitStruct.OscillatorType = RCC_OSCILLATORTYPE_HSE;
    RCC_OscInitStruct.HSEState = RCC_HSE_ON;
    RCC_OscInitStruct.HSEPredivValue = RCC_HSE_PREDIV_DIV1;
    RCC_OscInitStruct.HSIState = RCC_HSI_ON;
    RCC_OscInitStruct.PLL.PLLState = RCC_PLL_ON;
    RCC_OscInitStruct.PLL.PLLSource = RCC_PLLSOURCE_HSE;
    RCC_OscInitStruct.PLL.PLLMUL = APP_PLL_MULTIPLIER;
    if (HAL_RCC_OscConfig(&RCC_OscInitStruct) != HAL_OK) {
        Error_Handler();
    }

    RCC_ClkInitStruct.ClockType = RCC_CLOCKTYPE_HCLK | RCC_CLOCKTYPE_SYSCLK |
                                  RCC_CLOCKTYPE_PCLK1 | RCC_CLOCKTYPE_PCLK2;
    RCC_ClkInitStruct.SYSCLKSource = RCC_SYSCLKSOURCE_PLLCLK;
    RCC_ClkInitStruct.AHBCLKDivider = RCC_SYSCLK_DIV1;
    RCC_ClkInitStruct.APB1CLKDivider = APP_APB1_DIVIDER;
    RCC_ClkInitStruct.APB2CLKDivider = APP_APB2_DIVIDER;
    if (HAL_RCC_ClockConfig(&RCC_ClkInitStruct, APP_FLASH_LATENCY) != HAL_OK) {
        Error_Handler();
    }
}

/* USER CODE BEGIN 4 */
void HAL_TIM_PeriodElapsedCallback(TIM_HandleTypeDef *htim)
{
    if (htim->Instance == TIM4) {
        BSP_Time_OnTim4Overflow();
    }
}

void HAL_UART_RxCpltCallback(UART_HandleTypeDef *huart)
{
    BSP_Uart_OnRxComplete(huart);
}

void HAL_UART_TxCpltCallback(UART_HandleTypeDef *huart)
{
    BSP_Uart_OnTxComplete(huart);
}

void HAL_UART_ErrorCallback(UART_HandleTypeDef *huart)
{
    BSP_Uart_OnError(huart);
}
/* USER CODE END 4 */

void Error_Handler(void)
{
    /* USER CODE BEGIN Error_Handler_Debug */
    /* 普通 HAL/初始化错误发生在 PWM 已成功启动后时，先尽力让两桥 coast；
     * HardFault、复位与掉电仍必须依靠经实测的硬件失效保护。 */
    BSP_Board_EmergencyCoast();
    __disable_irq();
    while (1) {
        /* 若需生产级硬故障诊断，请加独立看门狗和故障记录；不要在此驱动电机。 */
    }
    /* USER CODE END Error_Handler_Debug */
}

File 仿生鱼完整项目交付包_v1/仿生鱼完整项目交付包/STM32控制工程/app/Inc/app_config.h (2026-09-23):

/**
 * @file app_config.h
 * @brief 本工程全部可调参数的唯一入口。
 *
 * 电机采用固定间隔、低占空比换相，只提供开/停控制，不声明实测机械 RPM。
 */
#ifndef APP_CONFIG_H
#define APP_CONFIG_H

/* 时钟：外部晶振标称值必须与实际板卡一致；此处 8 MHz 为常见值，待实测。 */
#define CFG_HSE_VALUE_HZ                         8000000UL
#define CFG_PLL_MULTIPLIER                        9UL
#define CFG_SYSCLK_HZ                            72000000UL
#define CFG_APB1_DIVIDER                          2UL
#define CFG_APB2_DIVIDER                          1UL
/* F1 在 APB 预分频不为 1 时，通用定时器时钟为 PCLK 的两倍。 */
#define CFG_APB1_PCLK_HZ                          (CFG_SYSCLK_HZ / CFG_APB1_DIVIDER)
#define CFG_APB1_TIMER_CLOCK_HZ                   ((CFG_APB1_DIVIDER == 1UL) ? \
                                                     CFG_APB1_PCLK_HZ : (CFG_APB1_PCLK_HZ * 2UL))

/* 串口和协议资源。所有数组均为固定大小，不使用动态内存。 */
#define CFG_UART_BAUD                            115200UL
#define CFG_ESP_RX_RING_BYTES                    256U     /* 必须为 2 的幂 */
#define CFG_UART_TX_RING_BYTES                   512U     /* 必须为 2 的幂 */
#define CFG_PROTOCOL_PAYLOAD_MAX                 192U
#define CFG_PROTOCOL_MAX_FIELDS                  16U
#define CFG_PROTOCOL_FRAME_TIMEOUT_MS            250UL    /* 收到 '<' 后的最大组帧静默时间 */

/* ESP-01S AT 固件的独立 AP/TCP 连接参数。 */
#define CFG_ESP_AP_SSID                          "BionicFish-AP"
#define CFG_ESP_AP_PASSWORD                      "12345678"
#define CFG_ESP_AP_IP                            "192.168.4.1"
#define CFG_ESP_AP_NETMASK                       "255.255.255.0"
#define CFG_ESP_TCP_PORT                         9000U
/* TCP 服务端并发连接上限（AT+CIPSERVERMAXCONN）。
 * 必须是 4：浏览器一次请求至少会开两条连接（页面本体 + /favicon.ico），
 * 上限为 1 时第二条会被拒从而让页面加载不稳定。
 * 固件仍然只接受一个"控制客户端"，多余连接按原有 reject_mask 逻辑立即关闭。 */
#ifndef CFG_ESP_MAX_CLIENTS
#define CFG_ESP_MAX_CLIENTS                      4U
#endif

/* Wi-Fi 工作模式（AT+CWMODE）：
 *   2 = 仅 SoftAP（**当前选定值**；手机必须加入 BionicFish-AP，但手机会失去外网）
 *   3 = AP + STA 并存（**当前不可用，见下方警告**）
 *
 * ⚠️ 2026-09-23 重大回归修复：本宏在 v0.5 引入时默认写成了 3，导致 IP 直连网页
 * 控制页彻底打不开。原因是**配置自相矛盾**：
 *     SET_MODE 下发 AT+CWMODE=3（要 AP+STA 双模），
 *     但固件**从不下发 AT+CWJAP**（见下方注释），STA 侧永远拿不到凭据。
 * ESP-01S 于是反复去连 flash 里残留的旧 AP，落成 sta=0.0.0.0；双模下模块内存
 * （仅 1MB flash）还要同时维护 AP 的 DHCP 服务器与 CIPSERVERMAXCONN 个 socket
 * 槽位，最终导致客户端拿不到 IP / AP 转发失效。
 *
 * v0.5 之前的版本（提交 9b97230）**根本没有本宏**，SET_MODE 写死 AT+CWMODE=2
 * （纯 AP），因此网页一直正常 —— 这正是"下午改代码之前是好的"的原因。
 * 若要重新启用 3，**必须同时实现 AT+CWJAP 下发**，否则 3 永远是坏配置。
 *
 * 实测环境：ESP-01S，AT 1.7.4.0 / SDK 3.0.5-dev，8Mbit(512KB+512KB)。 */
#ifndef CFG_ESP_WIFI_MODE
#define CFG_ESP_WIFI_MODE                        2U
#endif

/* 外部网络（STA）凭据。仅在 CFG_ESP_WIFI_MODE 含 STA 位时使用。
 * ⚠️ 明文写入源码；对外交付前应清空为 ""，由使用者自行填写。 */
#ifndef CFG_ESP_STA_SSID
#define CFG_ESP_STA_SSID                         "CTGU-T-Web"
#endif
#ifndef CFG_ESP_STA_PASSWORD
#define CFG_ESP_STA_PASSWORD                     "c+gu-+-web209"
#endif

#if (CFG_ESP_WIFI_MODE != 2U) && (CFG_ESP_WIFI_MODE != 3U)
#error "CFG_ESP_WIFI_MODE 只能是 2（仅 AP）或 3（AP+STA）。"
#endif
/* 注意：C 预处理器无法比较字符串，因此这里**不做**"SSID 不能为空"的编译期断言。
 * 当前固件也尚未下发 AT+CWJAP_CUR，STA 侧依赖模块 flash 里已保存的凭据自动重连；
 * 上面两个宏目前只作为记录，供后续"由固件自己配网"时使用。 */

/* 周期与失联策略（均需整机试验后确认）。 */
#define CFG_LINK_TIMEOUT_MS                      1000UL
#define CFG_STATUS_PERIOD_MS                     200UL
#define CFG_JY61P_SAMPLE_PERIOD_MS               50UL
#define CFG_OLED_FRAME_PERIOD_MS                 200UL
#define CFG_OLED_RETRY_MS                        2000UL
#define CFG_OLED_BOOT_DELAY_MS                   200UL
#define CFG_BUTTON_DEBOUNCE_MS                   30UL
#define CFG_SERVO_CENTER_ON_LINK_TIMEOUT         1U

/* 调试模式：让板载 K1(PB0)/K2(PB1)/K3(PA8) 在上位机不可用时直接驱动执行器。
 *   K1 切换 M1 驱动：按一次开始转，再按一次停止
 *   K2 舵机左转 CFG_SERVO_SAFE_MIN_DEG（-15°）
 *   K3 舵机右转 CFG_SERVO_SAFE_MAX_DEG（+15°）
 * 三个键均为低电平有效、内部上拉，按"按下沿"触发一次动作。
 * 注意：没有任何按键能控制 M2。
 *
 * ⚠️ 它有意放开"无链路即无运动"这条看门狗保证：K1 启动的转动会一直持续，直到再按
 * 一次 K1、或上位机链路超时触发失效保护。上位机仍然拥有最高优先级——任何被接受的
 * 远端命令都会立刻覆盖本地动作。仅用于台架调试，下水前必须设为 0。 */
#ifndef CFG_DEBUG_BUTTONS_ENABLED
#define CFG_DEBUG_BUTTONS_ENABLED                1U
#endif

/* TIM2：驱动两路 TB6612 H 桥的 PWM 载波。
 *
 * 2026-09-23 变更：PWM 周期由 20 kHz（50 µs）改为 **2 s 一周期**（0.5 Hz）。
 * 原因：台架发现 TB6612 无法可靠驱动直流减速电机，怀疑 PWM 边沿过密导致
 * 桥臂无法稳定使能。改为慢周期后，一个周期内的高电平是「一整段连续导通」，
 * 电机看到的是近似直流，而不是 20 kHz 斩波。
 *
 * 计算：TIM2 在 APB1 上，APB1=SYSCLK/2=36 MHz 时定时器时钟为 72 MHz。
 *       PSC=7199 → 计数频率 = 72 MHz / 7200 = 10 kHz
 *       ARR=19999 → 周期 = 20000 / 10 kHz = 2 s
 * 占空比仍由 CCR 给出：满速 100% → CCR=ARR+1（恒高，整周期导通，
 * 慢周期下这就是「连续直流」）；低速挡 60% → CCR=ARR*60/100。
 *
 * ⚠️ 慢周期只对「>0 且 <100」的占空比有意义：此时会出现「导通一长段、
 * 断开一长段」的脉动，电机会明显一顿一顿。若不需要调速，优先用 100%。 */
#define CFG_MOTOR_PWM_HZ                         1UL     /* 名义占位：见下方静态校验 */
#define CFG_MOTOR_TIM_PRESCALER                  7199U
#define CFG_MOTOR_TIM_PERIOD                     19999U
/* 实际 PWM 频率（0.5 Hz = 2 s 周期）。供文档/测试引用，不参与定时器换算。 */
#define CFG_MOTOR_PWM_PERIOD_MS                  2000UL
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

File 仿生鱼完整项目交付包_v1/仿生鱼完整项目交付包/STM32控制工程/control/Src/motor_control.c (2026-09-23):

#include "motor_control.h"

#include <string.h>

#include "app_config.h"
#include "bsp_board.h"

/* 本文件只负责「一条命令  两个 H 桥的 IN1/IN2 与占空比」，没有任何换相节拍。
 * 两路的**占空比与使能互相独立**：CFG_MOTOR_A_* 只影响 M1，CFG_MOTOR_B_* 只影响 M2，
 * 因此可以单独禁用其中一路、或者给两路配不同占空比。
 *
 * 2026-09-23：占空比改为**运行时两挡**（满速 95% / 低速 60%），由 BSP 的
 * BSP_Board_SetDutyMode 统一持有。这里不再直接引用编译期常量。 */

/* 取当前挡位对应的占空比。挡位由上层（网页/按键）切换，这里是唯一读取点。 */
static uint8_t CurrentDutyPercent(void)
{
    return BSP_DutyPercentFor(BSP_Board_GetDutyMode());
}

/* 把一路方向命令落到一个 H 桥：F/R 给方向 + 当前占空比；
 * 其余（含 S、非法枚举值、该路被禁用）一律 coast。
 * coast 的桥组合是 IN1=IN2=低 + PWM 恒高，永远不会产生 IN1=IN2=高的 brake 组合。 */
static void ApplyBridgeA(MotorController *motor, BfMove direction)
{
    motor->motor_a = BF_MOVE_STOP;
    if (CFG_MOTOR_A_ENABLED == 0U) {
        BSP_BridgeA_Coast();
        return;
    }
    switch (direction) {
    case BF_MOVE_FORWARD:
        BSP_BridgeA_Set(BSP_BRIDGE_FORWARD, CurrentDutyPercent());
        motor->motor_a = BF_MOVE_FORWARD;
        break;
    case BF_MOVE_REVERSE:
        BSP_BridgeA_Set(BSP_BRIDGE_REVERSE, CurrentDutyPercent());
        motor->motor_a = BF_MOVE_REVERSE;
        break;
    case BF_MOVE_STOP:
    default:
        BSP_BridgeA_Coast();
        break;
    }
}

static void ApplyBridgeB(MotorController *motor, BfMove direction)
{
    motor->motor_b = BF_MOVE_STOP;
    if (CFG_MOTOR_B_ENABLED == 0U) {
        BSP_BridgeB_Coast();
        return;
    }
    switch (direction) {
    case BF_MOVE_FORWARD:
        BSP_BridgeB_Set(BSP_BRIDGE_FORWARD, CurrentDutyPercent());
        motor->motor_b = BF_MOVE_FORWARD;
        break;
    case BF_MOVE_REVERSE:
        BSP_BridgeB_Set(BSP_BRIDGE_REVERSE, CurrentDutyPercent());
        motor->motor_b = BF_MOVE_REVERSE;
        break;
    case BF_MOVE_STOP:
    default:
        BSP_BridgeB_Coast();
        break;
    }
}

void Motor_Init(MotorController *motor)
{
    if (motor == 0) {
        return;
    }
    /* BF_MOVE_FORWARD 的枚举值就是 0，memset 之后必须显式写回 STOP，
     * 否则"刚初始化"会被当成"两路都在前进"。 */
    memset(motor, 0, sizeof(*motor));
    motor->motor_a = BF_MOVE_STOP;
    motor->motor_b = BF_MOVE_STOP;
    BSP_BridgeA_Coast();
    BSP_BridgeB_Coast();
}

void Motor_SetDirections(MotorController *motor, BfMove a, BfMove b)
{
    if (motor == 0) {
        return;
    }
    /* 顺序落地，互不覆盖：a 只写 motor_a/桥 A，b 只写 motor_b/桥 B。 */
    ApplyBridgeA(motor, a);
    ApplyBridgeB(motor, b);
}

void Motor_ApplyCommand(MotorController *motor, const BfRemoteCommand *command)
{
    if ((motor == 0) || (command == 0)) {
        return;
    }
    /* 一条命令同时落地两路：M1 取 move、M2 取 m2。 */
    Motor_SetDirections(motor, command->move, command->m2);
}

void Motor_ApplyFailsafe(MotorController *motor)
{
    Motor_SetDirections(motor, BF_MOVE_STOP, BF_MOVE_STOP);
}

void Motor_SetRunning(MotorController *motor, bool run)
{
    if (motor == 0) {
        return;
    }
    /* 只动 M1；M2 保持它当前的方向状态不变。 */
    ApplyBridgeA(motor, run ? BF_MOVE_FORWARD : BF_MOVE_STOP);
}

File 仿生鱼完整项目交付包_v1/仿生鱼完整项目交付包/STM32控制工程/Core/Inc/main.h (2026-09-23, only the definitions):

#define TB6612_PWMA_Pin       GPIO_PIN_0
#define TB6612_PWMA_GPIO_Port GPIOA
#define TB6612_PWMB_Pin       GPIO_PIN_1
#define TB6612_PWMB_GPIO_Port GPIOA
#define TB6612_AIN1_Pin       GPIO_PIN_12
#define TB6612_AIN1_GPIO_Port GPIOB
#define TB6612_AIN2_Pin       GPIO_PIN_13
#define TB6612_AIN2_GPIO_Port GPIOB
#define TB6612_BIN1_Pin       GPIO_PIN_14
#define TB6612_BIN1_GPIO_Port GPIOB
#define TB6612_BIN2_Pin       GPIO_PIN_15
#define TB6612_BIN2_GPIO_Port GPIOB
#define TB6612_STBY_Pin       GPIO_PIN_5
#define TB6612_STBY_GPIO_Port GPIOB
#define SERVO_SIG_Pin         GPIO_PIN_6
#define SERVO_SIG_GPIO_Port   GPIOA
#define OLED_SCL_Pin          GPIO_PIN_8
#define OLED_SCL_GPIO_Port    GPIOB
#define OLED_SDA_Pin          GPIO_PIN_9
#define OLED_SDA_GPIO_Port    GPIOB
#define JY61P_SCL_Pin         GPIO_PIN_6
#define JY61P_SCL_GPIO_Port   GPIOB
#define JY61P_SDA_Pin         GPIO_PIN_7
#define JY61P_SDA_GPIO_Port   GPIOB
#define KEY1_Pin              GPIO_PIN_0
#define KEY1_GPIO_Port        GPIOB
#define KEY2_Pin              GPIO_PIN_1
#define KEY2_GPIO_Port        GPIOB
#define KEY3_Pin              GPIO_PIN_8
#define KEY3_GPIO_Port        GPIOA
#define RUN_LED_Pin           GPIO_PIN_13
#define RUN_LED_GPIO_Port     GPIOC

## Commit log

2026-05-25 项目初始化：仿生鱼工程
    - 添加 README.md 项目说明文档
    - 添加 .gitignore 忽略规则（排除 env/密钥/编译产物等）
    - 包含项目计划书、需求文档等原始文件
2026-05-29 docs: 更新仿生鱼项目计划书 + 新增阶段A硬件采购清单
    [仿生鱼阶段A硬件清单.xlsx, 仿生鱼阶段A采购清单.xlsx, 仿生鱼阶段A采购清单_v1.1.xlsx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]
2026-05-30 docs: 升级至v3版本 - 通信方案从有线改为ESP32无线中继(2.4G背鳍天线)
2026-05-30 docs: 升级至v3.1 - 确定仿生虎鲸(50-60cm)、防水电机曲柄摇杆推进、舵机齿轮组联动背鳍尾腰转向、腹鳍独立控制
2026-06-04 更新：补充采购清单v3、项目计划书v3.2，清理冗余整理版文件
    [仿生鱼阶段A采购清单_v2.xlsx, 仿生鱼阶段A采购清单_v2_整理版.xlsx, 仿生鱼阶段A采购清单_v3.xlsx]
2026-06-17 chore: 项目同步与采购清单更新
    [仿生鱼二组采购清单（图片仅兼容office）.xlsx, 仿生鱼阶段A采购清单_v3.xlsx, 仿生鱼阶段A采购清单_v4 (version 1).xlsb.xlsx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]
2026-06-25 feat: v0.1.5 机构件建模 & HarmonyOS上位机源码
    [00_crank_rocker_assembly.step, 01_frame_tail_motor_support.step, 02_motor_crank.step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]
2026-06-25 refactor: 上位机目录重命名 & 新增尾鳍建模 & 电源方案
    [尾鳍1.STL, 尾鳍2.STEP, 尾鳍2.STL]
2026-07-06 📸 新增实物图片，更新尾部支撑建模
    [尾部支撑.SLDPRT]
2026-07-29 docs: 补写 v0.1.6 更新日志（7月6日遗漏提交）
2026-09-07 docs: 更新 CHANGELOG 至 v0.2.0（8/22-9/2：外壳复刻/结构建模/STM32拓展板）
2026-09-07 feat(建模): 追鲨一号外壳复刻v1与结构件迭代（尾部支撑V4R/鱼体第二关节/快拆架/虎鲸三视图等）
    [00_crank_rocker_assembly.step, 01_frame_tail_motor_support.step, 02_motor_crank.step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]
2026-09-07 feat(电子信息): STM32拓展板原理图与引脚分配、ESP32-STM32通信方案、电控设计文档
2026-09-07 chore(素材): 追鲨一号建模参考图、PCB参考图、视频关键帧提取脚本与天河星logo
    [fullassembly_wp.SLDASM]
2026-09-07 feat(交付): 仿生鱼完整项目交付包 v0.2.0（含 Android 上位机工程、交付说明等）
2026-09-07 chore: 补充根目录快拆架模型；.gitignore 增加 SolidWorks ~$ 锁文件规则
    [快拆架.SLDPRT]
2026-09-07 docs: 讲演实物图归档
2026-09-07 docs: 补充 v0.2.0 交付包小节并修正 commit 计数
2026-09-07 chore: 清理仓库中已移除的临时文件与旧交付包，gitignore同步
    [fullassembly_wp.SLDASM, 仿生鱼二组采购清单（图片仅兼容office）.xlsx, 仿生鱼阶段A硬件清单.xlsx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]
2026-09-07 chore: 补充建模快拆架 SLDPRT
    [快拆架.SLDPRT]
2026-09-07 release: 仿生鱼完整项目交付包 v0.3.1，CHANGELOG 补充 v0.3.1 发布说明
    [TEST-BionicFishApi35(AVD) - 15-_app-.xml]
2026-09-07 chore: gitignore 忽略讲演实物图与建模参考素材目录
2026-09-07 docs: 恢复项目 README（清理时误删，从历史补回）
2026-09-09 fix: stabilize TCP control and simplify fixed low-speed propulsion
    Use STM32 + ESP-01S AT/TCP + Android as the active control chain.
    Handle AT setup, stream framing, send completion, connection recovery and failsafe stops.
    Run the TB6612 stepper at fixed 10% PWM and 50 ms commutation; remove RPM calibration gates and speed selection.
    Recover OLED/IMU failures, restore missing Android theme values, and keep the OLED page layout.
    Pin reproducible firmware dependencies, fix flashing parameters, and update the current project documentation.
    Validation: 17/17 CTest; Arm build and clean rebuild with identical BIN; 56/56 Android unit tests; 23/23 MuMu instrumentation tests; lint 0 errors; 6/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
    [AsciiProtocol.kt, BionicFishAppTest.kt, BionicFishViewModel.kt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]
2026-09-23 feat(v0.5): 2s 慢周期 PWM + 95%/60% 双挡位 + 舵机 ±15° + 网页控制页重做
    问题 #1：TB6612 有 12V、STBY 已接高却带不动直流减速电机。
    根因：100% 占空比在 STM32F1 上落成 CCR > ARR，比较输出恒高、永不翻转；
    TB6612 的 PWM 输入需要持续开关边沿维持高侧自举驱动。
    处置：
    - TIM2 载波由 20 kHz 改为 2 s 慢周期（PSC=7199 / ARR=19999）
    - 满速挡占空比 100% -> 95%（保证每周期有一次完整低电平沿；95% x 12V = 11.4V）
    - 新增低速挡 60%（CFG_MOTOR_LOW_DUTY_PERCENT）
    - SetBridgeCompare 改为写 CCR 后立即发 UG 事件强制提交，
    避免按 2 s 自然更新等待导致单次调用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
    [AsciiProtocol.kt, BionicFishAppTest.kt]
2026-09-23 chore: 移除旧版交付目录 仿生鱼完整项目交付包_v0.3.1
    该目录内容已被 仿生鱼完整项目交付包_v0.5 完整取代
    （v0.5 含 STM32 控制工程、安卓 v0.5.0 交付包与原始资料），
    保留只会造成两套源码并存、难以判断哪份是当前基线。
    历史仍可通过 git 回溯：
    git show 9b97230:仿生鱼完整项目交付包_v0.3.1/...
    [TEST-BionicFishApi35(AVD) - 15-_app-.xml]
2026-09-23 docs(v0.5): 安卓端改造方案对齐 95%/60% 挡位制与 2s 慢周期
    - §1.1 占空比与调速口径重写：不再是"编译期固定 100% / step_speed 不改输出"，
    改为"满速挡 95% + 低速挡 60%，step_speed 是挡位选择器"
    - 新增 §1.1.1：2 s 慢周期 + 95% 的根因分析（100% 恒高无下降沿 -> 自举不刷新）
    - §3.6 文案订正改为"挡位选择器"，并提示低速挡是两路共用、不要做成单路控件
    - §6.4 文档同步表改为带状态标记（固件侧 5 份已完成，安卓侧 5 份待改）
    - §7 风险表新增：实板带载未验证、2 s 边沿稀疏性、TB6612 无过流保护
    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
2026-09-23 docs(v0.5): 清除源码注释里的步进口径与过时挡位描述
    - app_config.h 调试键注释：K1「步进驱动」→「M1 驱动」；K2/K3 舵机 ±20° → ±15°；
    补「没有任何按键能控制 M2」
    - app.c ServiceI2cScan 注释：「步进停止」→「M1 停止」
    - http_ui.c / http_ui.h 的 speed= 注释：由「兼容字段，已不改变占空比」
    改为「占空比挡位选择器，60=低速挡 / 100=满速挡」
    纯注释改动。重新交叉构建后 BIN 哈希与之前完全一致
    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
2026-09-23 fix(v0.5): 修复 CWMODE 回归导致 IP 直连网页打不开（3 → 2 纯 AP）
    现象：手机连上 BionicFish-AP 后，http://192.168.4.1:9000/ 完全打不开。
    根因：CFG_ESP_WIFI_MODE 在 v0.5 引入时默认写成 3（AP+STA），但固件从不下发
    AT+CWJAP，STA 侧永远拿不到凭据。ESP-01S 反复去连 flash 残留旧 AP，落成
    sta=0.0.0.0；双模下模块还要同时维护 AP-DHCP 与 CIPSERVERMAXCONN 个 socket
    槽位，最终导致客户端拿不到 IP、AP 转发失效。
    跨提交对比（决定性证据）：
    旧版 9b97230 SET_MODE 写死 AT+CWMODE=2，无该宏 → 网页正常
    v0.5 f30f511 宏默认 3U + 新增 SET_CHECK_STA_IP → 网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
    [app_config.h]
2026-09-23 chore: gitignore 忽略 build-fw-fix/ 与 build-host-fix/
2026-09-23 fix(v0.5): HTTP_RAW_BYTES 小于 HTTP_RESPONSE_BYTES 导致网页响应静默发不出去
    现象：CWMODE 修复并烧入实板后，手机连上 BionicFish-AP 仍打不开
    http://192.168.4.1:9000/ 。串口却显示 server=1、error=OK、reset=0、uloss 稳定。
    根因：两个缓冲区尺寸对不上。
    app.c:507 response[] = HTTP_RESPONSE_BYTES = 4096
    esp_link.c L.raw[] = HTTP_RAW_BYTES = 3584 ← 少 512
    v0.5 重做网页后 kPage 涨到 3652 字节（ELF 符号表 0x0e44），加 123 字节响应头
    与 4 位 Content-Length，实际响应总长 3779 字节 > 3584。EspLink_SendRaw 的第一道
    守卫 `length > sizeof(L.raw)` 因此成立并直接 return false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
    [esp_link.c]
2026-09-24 feat(repo): 开源尾段结构件 鱼尾装配/，建模工作区不再入库
    结构件开源
    - 新增顶层目录 鱼尾装配/：12 个尾段零件与装配体（左右支撑、套筒、摇杆、
    moto shef 电机座、U 型件、快拆架、防水盒快拆、鱼体第二关节、装配体）
    - 新增 鱼尾装配/README.md：零件清单（区分当前/历史版本）、曲柄摇杆传动
    说明、已废弃步进方案警告、打印装配提示
    - 剔除步进遗留件 42HS34-FS.STEP 与 步进支架.step（已并入建模工作区留档）
    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
    [100ml活塞底座.SLDPRT, 100ml活塞底座.STL, 3115舵机.SLDPRT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]
2026-09-24 docs(hw): 补全硬件电气设计章节，新增 电气设计说明/
    README 第三章升级为「硬件与电气设计」
    - 3.1 选型表新增 4 行：板级架构（核心板+拓展板）、调试烧录（SWD+CH340 双接）、
    ME6211 LDO、LM2596S DCDC、XT60/咪头双输入、5A 一次性保险丝
    - 3.1 开篇点明总体思路沿用 TI 杯电赛模组化范式
    - 新增 3.5 拓展板：32 针母座、UART/电机/舵机全排针扇出、全模组可拔换；
    3.5.2 详述板载 CH340 与 SWD 双接构成 AI Agent 可闭环调试环境
    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
2026-09-24 docs: 移除「十、验收状态与已知边界」整章
    按作者要求删去该章（含 10.1 已通过验证、10.2 尚未完成验证、
    10.3 已知待改进项、10.4 安全须知）。
    - 目录移除对应条目，章节由九直接接「附：开发历程」
    - 1.1 节末尾的范围声明不再指向该章，改为就地说明下水前须确认事项
    - 全文已无指向该章的链接与锚点残留
2026-09-24 docs: 新增复刻指南（硬件制造 / 通信调试 / 电控编写）
    docs/复刻指南/ 共 4 文件 930 行：
    - README.md（索引）：三方向导航、复刻顺序与依赖关系、
    开篇先列三条最易踩的坑（95% 占空比、CWMODE 必须为 2、保险丝不防反接）、
    参考材料索引表
    - 硬件制造.md：采购清单（按功能分组，标注必需规格与坑）、
    电源链路与引脚接线、三条接线纪律、尾段与外売打印装配、唧筒装配、
    上电前检查清单、首次上电顺序、常见问题、安全须知
    - 通信调试.md：链路全貌、双通道调试接入（先装「眼睛」）、
    ESP-01S 固件与 AT 配置（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
2026-09-24 docs(readme): 首屏加入实拍图与演示动图，补充 AI Agent 联合开发说明
    - 首屏新增实拍展示：下水实拍、泳池演示动图（5 s 循环，470 px）、
    整机俯视、拓展板实装、外观渲染与打印实物
    - 原 H.265 演示视频转码为 H.264 MP4（docs/media/demo.mp4），
    GitHub 与主流浏览器可直接在线播放；动图由同一视频裁取
    - 3.5 拓展板补 PCB 3D 设计视图；4.3 补鱼体 CAD 正视图；
    4.5 补尾部传动 CAD 装配图
    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
2026-09-24 docs: 项目口径调整为「项目组主导 · 组员协作」，并更新整机下水实测状态
    - README.md：署名口径由「一人主导 / 全栈单人造」改为「项目组主导、组员协作、AI Agent 辅助」，
    同步修订开篇定位、设计归属说明与致谢段落
    - README.md：验证状态由「尚处于台架验证阶段，未完成整机下水验收」更新为
    「已在泳池 / 静水环境完成整机下水运行实测」，并新增说明：软件层证据与整机下水属两套独立证据
    - README.md：开发历程由三阶段扩为四阶段，新增「实机下水」阶段；下水流程新增第 8 步（下水运行要求）
    - README.md：唧筒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
2026-09-24 chore(发票): 采购发票目录移出版本控制并加入 .gitignore
    发票含抬头、税号、金额等敏感信息，不适合放在公开仓库。
    - .gitignore 新增 发票/ 规则
    - 将已跟踪的 发票/ 目录整体从索引移除（本地文件原样保留，历史提交不受影响）
    - 本次不再提交新增的发票照片（IMG_27452-27465.jpg）与 发票商品明细.xlsx
2026-09-24 chore(scripts): 新增仓库根目录「一键编译 + 烧录」脚本
    - 一条命令走完 CMake + Ninja + arm-none-eabi-gcc（WERROR=ON）编译，再由 ST-Link / SWD 烧录校验并复位运行
    - 支持 -SkipBuild / -SkipFlash / -FirmwareElf / -UnderReset 开关
    - 固件工程默认路径改为相对脚本自身位置解析，默认指向 v0.5 交付包 STM32控制工程，脚本置于仓库根目录即可直接使用
2026-09-25 release: v1.0.0 — 交付包升级为 v1，整机下水口径与仓库整备
    - 交付包目录 仿生鱼完整项目交付包_v0.5/ → 仿生鱼完整项目交付包_v1/，181 个文件内容零变更重命名
    - 同步 README、docs/复刻指南（README + 电控编写）、电气设计说明、烧录脚本 中的 20 处引用路径
    - 恢复并保留关键交付文档：交付说明.md、原始资料/STM32拓展板_2026-08-26_引脚分配.md、
    STM32控制工程/代码审查问题清单_2026-09-08.md、ESP01S_AP_UDP_Bridge/README.md
    - CHANGELOG 新增 v1.0.0 正式版章节，原「未发布」条目归入 v0.5.0
    [AsciiProtocol.kt, BionicFishAppTest.kt]
2026-09-25 docs(scripts): 修正烧录脚本注释中的交付包版本（v0.5 → v1）
    路径已在 v1.0.0 提交中指向 仿生鱼完整项目交付包_v1，此处补正行内注释措辞，避免误导。
2026-09-25 release(v1.0.0): 安卓交付包升级为 v5.0，并修正 .gitignore 误伤源码
    - 仿生鱼安卓_v0.5.0_交付包/ → 仿生鱼安卓_v5.0_交付包/：90 个文件零内容变更重命名
    - APK 重命名 BionicFish-v0.5.0.apk → BionicFish-v5.0.apk（内容未变）
    - 新增 Android 工程 DesignTokens.kt（v5.0 设计令牌源码）
    - .gitignore：*token* 规则会误伤 DesignTokens.kt，补 !DesignTokens.kt 例外放行
    - 本次内容与 v1.0.0 Release 已上传的附件（交付包 zip / APK）保持一致
    [AsciiProtocol.kt, BionicFishAppTest.kt]
2026-09-25 docs(readme): 文末新增「写在最后」寄语
    在「许可」章节后追加一段关于 AI Agent 与个人核心能力的思考：
    Agent 大幅提升个人全栈效率、让单人全栈成为可能的同时，也容易让初学者
    忽视基础项目能力的沉淀；工具负责快，人负责对。
